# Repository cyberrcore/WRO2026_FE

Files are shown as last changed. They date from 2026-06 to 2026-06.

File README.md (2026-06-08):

# WRO 2026 Future Engineers - Team CYBERRCORE

<p align="center">
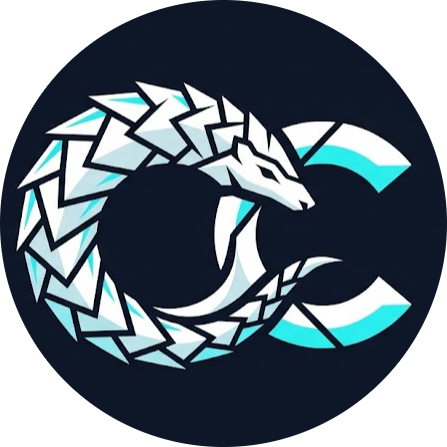
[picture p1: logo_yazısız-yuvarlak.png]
Team CYBERRCORE Logo
  
</p>

# 🏆 Turkish National 2nd Place - WRO 2026 FE

<p align="center">
Turkish robotics team building compact autonomous vehicles for<br>
<b>World Robot Olympiad™ Future Engineers 2026</b>
</p>

---

CYBERRCORE developed a compact autonomous vehicle designed for both the **Open Round** and **Obstacle Round**. Built through a short but intense engineering process, our robot combines **mechanical design**, **embedded control**, **computer vision**, and **sensor-based navigation** into a simple, reliable, and competition-ready system.

---

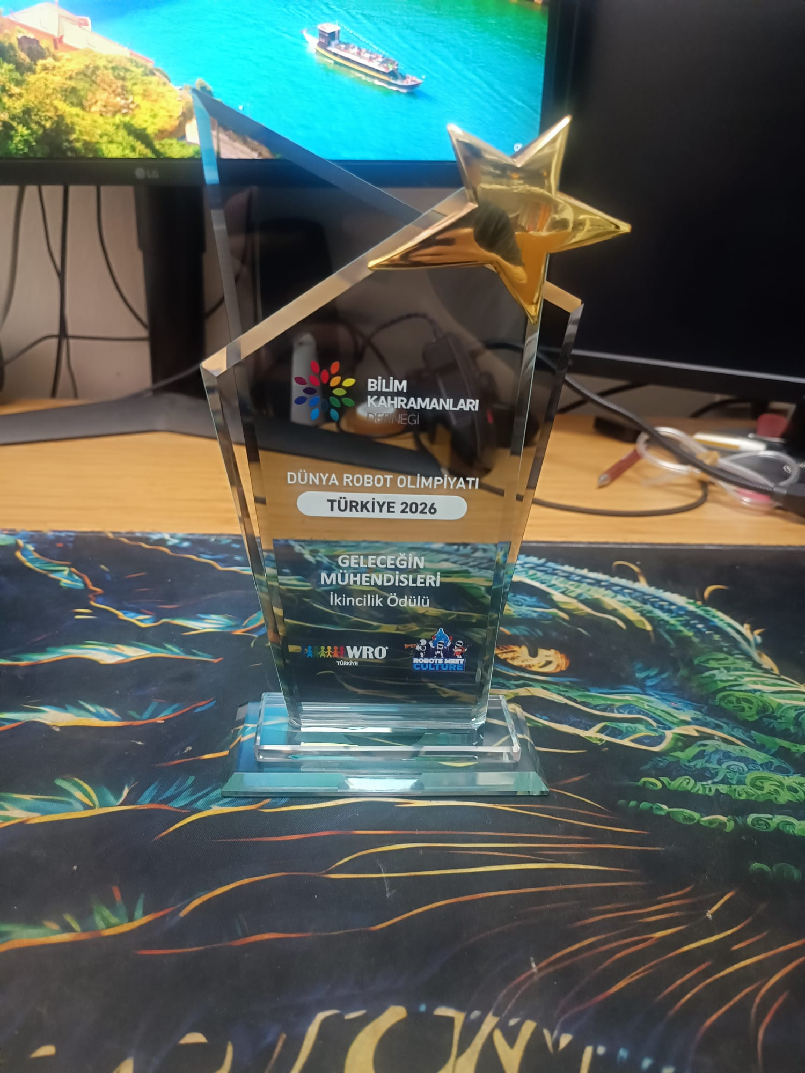
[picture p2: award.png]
Team CYBERRCORE Award


---

## Robot Documentation Preview

| Mechanical CAD | Electronics Wiring |
| --- | --- |
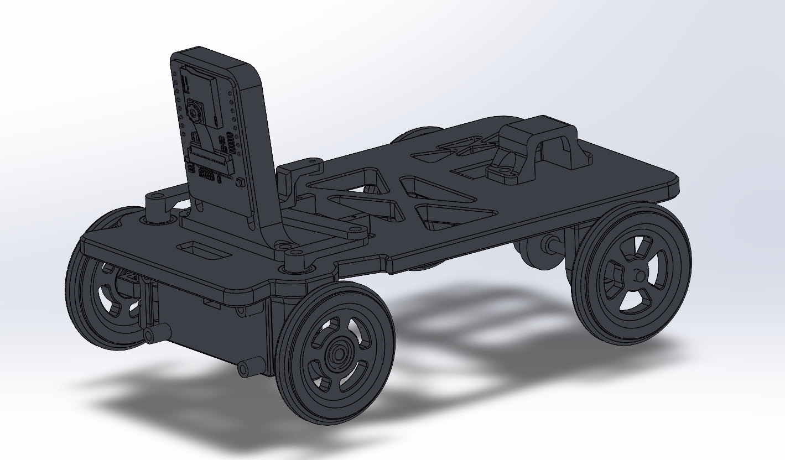
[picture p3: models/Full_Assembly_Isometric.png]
Full robot CAD assembly
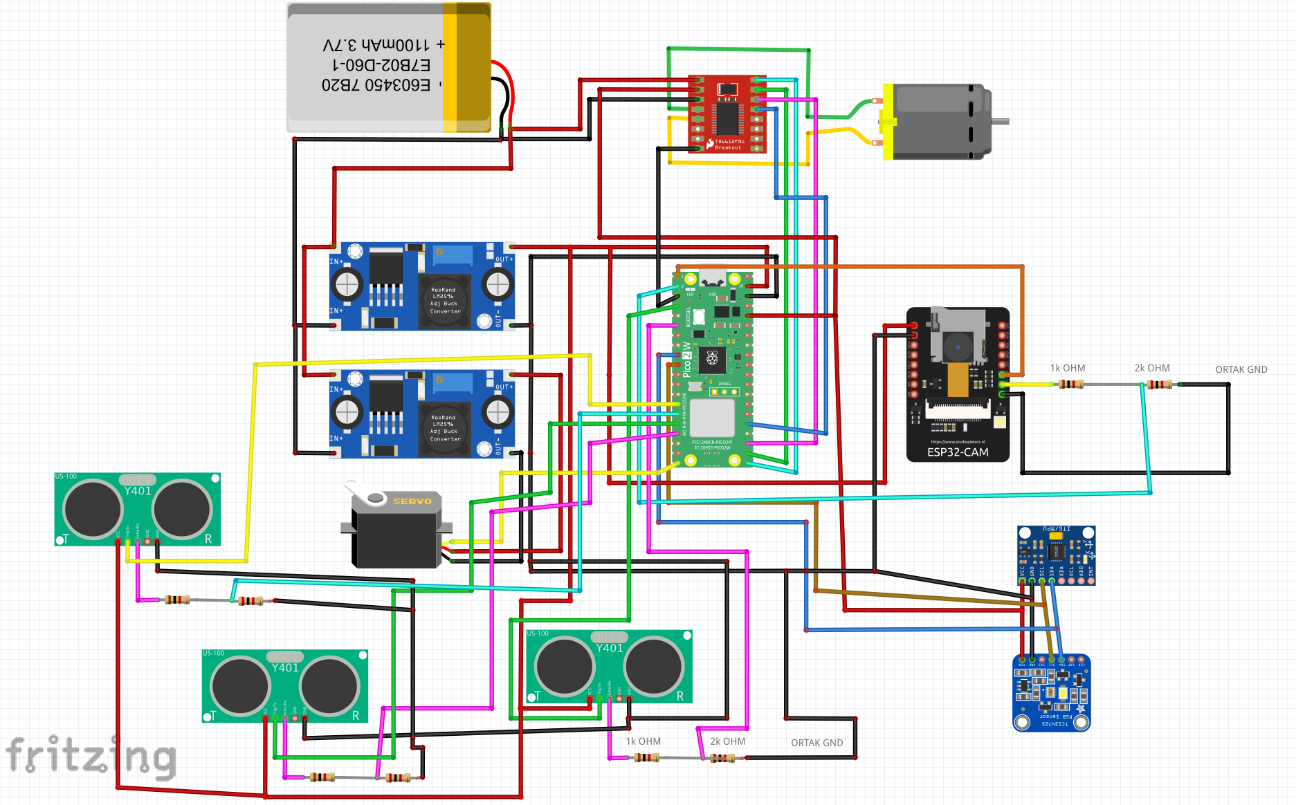
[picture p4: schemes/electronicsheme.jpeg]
Complete electronics wiring scheme
|  |  |

| Bench Build | Track Testing |
| --- | --- |
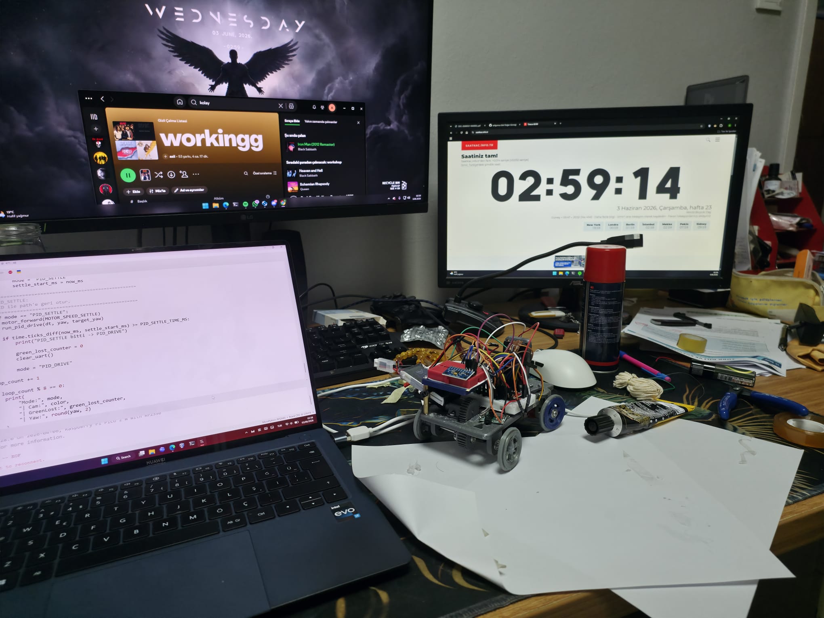
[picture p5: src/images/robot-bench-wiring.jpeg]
Robot bench wiring and development setup
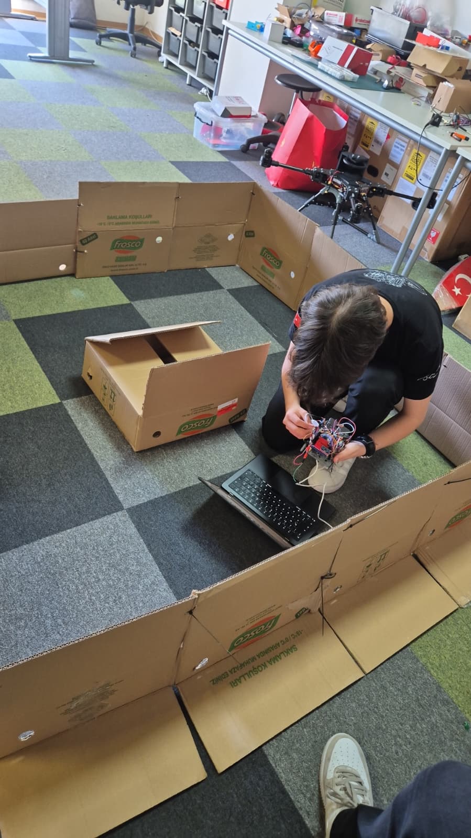
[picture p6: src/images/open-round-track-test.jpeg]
Open-round track testing
|  |  |

---

## Repository Map

| Folder / File | Contents | Why it matters |
| --- | --- | --- |
| [`src/`](src/) | ESP32-CAM firmware, Raspberry Pi Pico MicroPython scripts, state-machine logic, PID control, test utilities | Shows how the autonomous behavior is implemented and tuned |
| [`schemes/`](schemes/) | Full wiring scheme, electronics BOM, signal tables, voltage rails, current budget | Allows judges or other teams to reproduce the electrical system safely |
| [`models/`](models/) | CAD renders, mechanical explanations, chassis, steering, drivetrain, mounts, wheels | Documents the robot's physical design and engineering reasoning |
| [`models/STL/`](models/STL/) | Print-ready STL files for all custom mechanical parts | Enables direct reproduction of the 3D-printed robot body |
| [`v-photos/`](v-photos/) | Six required robot views: front, rear, top, bottom, left, right | Physical evidence of the built prototype |
| [`t-photos/`](t-photos/) | Official and fun team photos | Team identification |
| [`video/`](video/) | Links to open-round and obstacle-round run videos | Demonstrates real robot performance |
| [`CYBERRCORE_Technical_Documentation.pdf`](CYBERRCORE_Technical_Documentation.pdf) | Complete technical report | Printable engineering documentation |

---

## Engineering Rubric Coverage

| WRO judging criterion | Repository evidence |
| --- | --- |
| Mobility and mechanical design | `models/README.md`, CAD previews, STL files, chassis layout, Ackermann steering, differential drivetrain |
| Power and sensor architecture | `schemes/README.md`, wiring scheme, BOM, voltage rails, signal tables, power budget |
| Software architecture | `src/README.md`, ESP32-CAM firmware, Pico MicroPython files, UART protocol, PID parameters |
| Obstacle strategy | Camera color detection, red/green target logic, obstacle state machine, gyro recovery |
| Repeatability and testing | Servo tuning script, camera UART test, validation tables, reproduction checklist |
| Engineering decisions | Trade-off tables explaining why each subsystem was selected |

---

## 1. System Overview

Team CYBERRCORE's robot is a fully autonomous four-wheeled vehicle built for WRO 2026 Future Engineers. The architecture is split into mechanical, electrical, and software subsystems so each part can be tested independently before full autonomous runs.

The robot uses:

| Subsystem | Technology | Role |
| --- | --- | --- |
| Main controller | Raspberry Pi Pico 2 W H | Runs MicroPython navigation, PID steering, sensor fusion, motor control, and lap counting |
| Vision module | ESP32-CAM | Detects red and green obstacles using RGB565 image processing |
| Motor driver | TB6612FNG | Controls the brushed DC drive motor with PWM and direction pins |
| Drive motor | 6 V micro DC motor | Provides rear-wheel propulsion through a spur-gear drivetrain |
| Steering | HD-1440A servo | Drives the front Ackermann steering linkage |
| Distance sensor | US-100 ultrasonic sensor | Detects walls, corners, and close-range safety distance |
| IMU / gyro | MPU6050 | Estimates yaw for 90 degree turns and heading recovery |
| Color sensor | TCS34725 | Backup / future validation module for color sensing |
| Battery | 2S 450 mAh 40C LiPo | Main power source, 7.4 V nominal and 8.4 V fully charged |
| Voltage regulation | 2x LM2596 / RT3505 buck converters | Separate logic and servo power rails |
| Mechanical structure | SolidWorks + FDM 3D printing | Custom chassis, mounts, gears, wheels, and steering parts |

### High-level control architecture

```mermaid
flowchart LR
    ESP[ESP32-CAM<br>RGB565 color detection] -->|UART 115200<br>RED / GREEN / NONE| PICO[Raspberry Pi Pico 2 W H<br>Navigation + PID + sensor fusion]
    US[US-100 Ultrasonic] --> PICO
    IMU[MPU6050 Gyro] --> PICO
    TCS[TCS34725 Backup Color Sensor] --> PICO
    PICO -->|PWM + Direction| TB[TB6612FNG Motor Driver]
    TB --> MOTOR[Rear DC Motor]
    PICO -->|50 Hz PWM| SERVO[HD-1440A Steering Servo]
    BAT[2S LiPo Battery] --> B1[Buck 1: 5 V Logic Rail]
    BAT --> B2[Buck 2: 5 V / 6 V Servo Rail]
    BAT --> TB
```

The ESP32-CAM handles vision separately so the Pico does not need to process camera frames. The Pico receives simple UART messages and combines them with ultrasonic distance and gyro yaw to decide when to drive straight, avoid obstacles, turn corners, recover heading, or stop after the required number of laps.

---

## 2. Mechanical Design

The mechanical platform is designed around three priorities:

1. **Low center of gravity** for stable driving at speed.
2. **Repeatable steering geometry** for consistent cornering.
3. **Easy reproduction** using printable CAD/STL files.

All custom mechanical components were designed in SolidWorks and manufactured using FDM 3D printing. PLA is used for prototyping, while PETG or ABS is recommended for competition versions where stronger temperature and impact resistance are useful.

---

### 2.1 Main Chassis

The main chassis uses a single-level flat-plate structure. This keeps the robot low and leaves enough surface area for electronics, wiring, motor placement, servo placement, and sensor mounts.

| Feature | Description |
| --- | --- |
| Architecture | Single-level flat plate |
| Center of gravity | Low CG improves stability during fast turns |
| Lightening cutouts | X-pattern triangular pockets reduce mass while preserving load paths |
| Standoff columns | Molded-in posts allow direct PCB and cover mounting |
| Subsystem zones | Dedicated areas for motor, servo, differential, and sensor brackets |
| Perimeter rail | Continuous edge flange supports external bracket attachment |
| Recommended print settings | 40-60% infill, gyroid pattern, layer lines perpendicular to primary stress direction |

The X-pattern cutouts reduce weight without removing material from the major structural paths. This helps the robot remain light enough for speed while still resisting flex during steering and drivetrain loads.

---

### 2.2 Steering System - 4-Part Ackermann Linkage

The front steering system uses an Ackermann-style linkage. In a turn, the inner front wheel needs to rotate at a sharper angle than the outer wheel because it travels around a smaller radius. The custom linkage is designed to make the front wheels point toward a common turning center, reducing tire scrub and improving repeatability.

| Part | Role | Key feature |
| --- | --- | --- |
| `Steer1` - Steering knuckle | Connects wheel spindle to chassis upright | L-shaped bracket; upper hole for servo pin and lower hole for chassis pivot |
| `Steer2` - Tie rod | Transmits servo motion to both front knuckles | Flat bar with equal-diameter holes; designed for low backlash |
| `Steer3` - Left arm | Converts servo rotation to left wheel angle | Asymmetric boss compensates for Ackermann geometry |
| `Steer4` - Right arm | Mirrored steering arm for the right side | Cylindrical boss for shaft engagement; mirrored from the left side |

This steering design is more complex than a simple direct-servo steering setup, but it gives more realistic vehicle behavior and better corner consistency.

---

### 2.3 Rear Drivetrain and Differential

The rear drivetrain uses a 1:1 spur-gear pair to transfer motor torque to the rear axle. The gear set uses **31-tooth to 31-tooth gears** with a **0.8 module**.

| Parameter | Value | Reason |
| --- | --- | --- |
| Gear module | 0.8M | Compact pitch suitable for small printed drivetrains |
| Tooth count | 31T : 31T | 1:1 ratio preserves motor RPM |
| Drive ratio | 1:1 | Prioritizes speed while relying on low vehicle mass for sufficient torque |
| Bearing type | 3x10x4 radial ball bearings | Reduces friction and improves lap-to-lap consistency |
| Differential | Custom printed differential | Allows rear wheels to rotate at different speeds during turns |

The differential is important because the inside and outside rear wheels travel different distances in a turn. Without differential action, the inside rear wheel can scrub against the floor, causing inconsistent cornering and possible heading errors.

---

### 2.4 Wheels and Tires

The front and rear wheels are designed differently because they have different jobs.

| Aspect | Front wheel | Rear wheel |
| --- | --- | --- |
| Hub type | Recessed bearing seat for press-fit 3x10x4 bearing | Direct shaft hub, no bearing |
| Spoke pattern | 4 spokes with intermediate web | 4 solid spokes, lighter |
| Function | Free rotation around a fixed spindle | Fixed to driven axle shaft |
| Tire fit | O-ring press-fit over outer rim flange | O-ring press-fit over outer rim flange |

The tires use an O-ring / torus profile with circumferential grip grooves. This makes tire replacement fast and keeps the rolling geometry consistent between test sessions.

---

### 2.5 Sensor and Electronics Mounts

The robot uses dedicated printed mounts for the camera, ultrasonic sensor, and motor. This improves repeatability because sensor angles and drivetrain alignment are defined by printed geometry instead of temporary hand placement.

| Mount | Key features |
| --- | --- |
| Camera mount `CamMount` | Tall vertical bracket, two vertical adjustment slots, angled forward lean for near-field obstacle detection, two M3 base holes |
| US-100 mount `US100_Mount` | Box bracket, square sensor cutout, side snap-tab retention, four corner mounting holes |
| Motor mount `motorMount` | U-bracket wrapping motor on three sides, snap-clip tool-free removal, two M3 base holes, built-in gear alignment |

The camera mount height can be adjusted to tune how early the ESP32-CAM sees obstacles. The ultrasonic mount keeps the US-100 facing forward so wall distance measurements stay consistent.

---

## 3. Electronics and Wiring

The electronics architecture separates motor power, logic power, and servo power to reduce noise and avoid brownouts. All modules share a common ground reference.

### 3.1 Bill of Materials

| Component | Quantity | Type | Description |
| --- | ---: | --- | --- |
| Raspberry Pi Pico 2 W H | 1 | Main MCU | MicroPython controller for steering, motor, sensors, and navigation |
| ESP32-CAM | 1 | Camera module | RGB565 color detection and UART obstacle reporting |
| TB6612FNG | 1 | Motor driver | PWM + direction control for brushed DC motor |
| 6 V micro DC motor | 1 | Drive motor | Rear-wheel propulsion through spur gears |
| HD-1440A servo | 1 | Steering servo | PWM-controlled Ackermann steering |
| US-100 ultrasonic sensor | 1 | Distance sensor | Wall detection, corner trigger, safety stop |
| MPU6050 | 1 | IMU / gyro | Yaw estimation for turns and heading recovery |
| TCS34725 | 1 | Color sensor | Backup / future color validation |
| LM2596 / RT3505 buck converter | 2 | Voltage regulator | Buck 1 for 5 V logic, Buck 2 for servo rail |
| 2S 450 mAh 40C LiPo | 1 | Battery | Main power source |
| On/off switch | 1 | Power switch | Manual power cut |
| 3x10x4 bearings | 4+ | Hardware | Front wheel and rear shaft support |
| M3 fasteners / washers | TBD | Hardware | Chassis, mounts, and brackets |

---

### 3.2 Power Architecture

The 2S LiPo battery provides **7.4 V nominal** and **8.4 V when fully charged**. It feeds three main destinations through the on/off switch:

1. Buck 1 input for the 5 V logic rail.
2. Buck 2 input for the servo rail.
3. TB6612FNG VM motor power input directly.

#### Main power input

| From | To | Voltage | Peak current | Notes |
| --- | --- | --- | --- | --- |
| 2S LiPo + | On/off switch input | 7.4-8.4 V | 2.5 A | Full-load peak across all rails |
| Switch output | Buck 1 input | 7.4-8.4 V | 0.6 A | Logic rail input |
| Switch output | Buck 2 input | 7.4-8.4 V | 1.0 A | Servo rail input |
| Switch output | TB6612FNG VM | 7.4-8.4 V | 1.0 A | Direct battery power for motor |
| 2S LiPo - | Common GND bus | 0 V | - | Shared ground reference |

#### Buck 1 - 5 V logic rail

| From | To | Voltage | Current | Notes |
| --- | --- | --- | --- | --- |
| Buck 1 OUT+ | Pico VBUS | 5.0 V | 50-100 mA | Powers Pico onboard 3.3 V regulator |
| Buck 1 OUT+ | ESP32-CAM 5V | 5.0 V | 100-400 mA | Camera current depends on operation |
| Buck 1 OUT+ | TB6612FNG VCC | 5.0 V | 1-5 mA | Logic supply only |

Total estimated Buck 1 output load: **400-500 mA**.

#### Buck 2 - servo rail

| From | To | Voltage | Current | Notes |
| --- | --- | --- | --- | --- |
| Buck 2 OUT+ | HD-1440A servo red wire | 5.0 V default, optional 6.0 V | 10-1000 mA | Up to 1 A peak under load |

Buck 2 should be set to **5 V by default**. A 6 V servo rail can be used for more steering torque and speed only if the wiring, servo, and regulator are verified to support it.

#### Pico 3.3 V sensor rail

| From | To | Voltage | Current | Notes |
| --- | --- | --- | --- | --- |
| Pico 3V3 OUT | TCS34725 VCC | 3.3 V | ~5 mA | Color sensor |
| Pico 3V3 OUT | MPU6050 VCC | 3.3 V | ~4 mA | Gyro + accelerometer |
| Pico 3V3 OUT | US-100 VCC | 3.3 V | ~20 mA | Ultrasonic measurement pulse |
| Pico GND | All sensor grounds | 0 V | - | Common reference |

Total estimated Pico 3.3 V sensor load: **30-40 mA**, within the Pico regulator capacity.

---

### 3.3 Signal and Data Lines

| From | To | Voltage | Notes |
| --- | --- | --- | --- |
| Pico GPIO 14 PWM | HD-1440A servo signal | 3.3 V | 50 Hz PWM, 1-2 ms pulse |
| Pico GPIO 16 PWM | TB6612FNG PWMA | 3.3 V | Motor speed control |
| Pico GPIO 17 | TB6612FNG AIN2 | 3.3 V | Motor direction |
| Pico GPIO 18 | TB6612FNG AIN1 | 3.3 V | Motor direction |
| Pico GPIO 19 | TB6612FNG STBY | 3.3 V | Must be HIGH to enable motor output |
| Pico GPIO 4 SDA | MPU6050 SDA / TCS34725 SDA | 3.3 V | Shared I2C data |
| Pico GPIO 5 SCL | MPU6050 SCL / TCS34725 SCL | 3.3 V | Shared I2C clock |
| Pico GPIO 10 | US-100 TRIG | 3.3 V | 10 microsecond trigger pulse |
| Pico GPIO 11 | US-100 ECHO | 3.3 V | Echo input |
| ESP32-CAM TX | 1k + 2k divider to Pico GPIO 1 RX | 5 V to 3.3 V | Level shift required |
| Pico GPIO 0 TX | ESP32-CAM RX | 3.3 V | Compatible with ESP32-CAM RX |

> Important: measure both buck converter outputs with a multimeter before connecting the Pico, ESP32-CAM, sensors, or servo.

---

### 3.4 Power Budget

| Rail | Consumers | Typical current | Peak current |
| --- | --- | ---: | ---: |
| Battery direct to TB6612FNG VM | DC motor | ~300 mA | 1.0 A |
| Buck 1 - 5 V logic | Pico + ESP32-CAM + TB6612FNG logic | ~250 mA | ~505 mA |
| Buck 2 - servo rail | HD-1440A servo | ~10 mA idle | 1.0 A |
| Pico 3.3 V out | MPU6050 + TCS34725 + US-100 | ~29 mA | ~40 mA |
| Total battery load | All rails combined | ~590 mA | ~2.5 A |

This power separation helps prevent motor and servo current spikes from resetting the logic boards.

---

## 4. Software Architecture

The software is divided between the ESP32-CAM and the Raspberry Pi Pico.

| File | Platform | Purpose |
| --- | --- | --- |
| `camera.cpp` | ESP32-CAM / Arduino C++ | RGB565 color detection for red and green obstacles; UART output |
| `camera_uart_blink.py` | Pico / MicroPython | Isolated UART receiver test; blinks LED on camera messages |
| `openround.py` | Pico / MicroPython | Open-round navigation with gyro-assisted 90 degree turns |
| `obstacleround.py` | Pico / MicroPython | Obstacle-round navigation, camera tracking, gyro recovery, lap counting |
| `servo_tune.py` | Pico / MicroPython | Servo center, direction, and steering tuning utility |

---

### 4.1 ESP32-CAM Vision System

The ESP32-CAM captures **QQVGA 160x120** RGB565 frames and scans the lower image region beginning at `ROI_Y_START = 30`. Pixels are sampled with a 2x2 step, converted from RGB565 to RGB888, and tested against threshold rules.

The output is sent to the Pico over UART at **115200 baud**.

#### UART protocol

One line is sent per frame:

```text
RED,<center_x>,<pixel_count>
GREEN,<center_x>,<pixel_count>
NONE
```

| Detection | Rule |
| --- | --- |
| Red | High red channel, low green/blue channels, red dominates other channels |
| Green | High green channel, limited red/blue channels, green dominates other channels |
| Priority | If both colors are visible, red is prioritized when red area is at least equal to green area |
| Minimum area | Color must exceed `RED_MIN_AREA` or `GREEN_MIN_AREA` before being reported |

The Pico does not process image frames directly. It only receives the detected color, horizontal center position, and pixel area.

---

### 4.2 Open Round Navigation

`openround.py` implements a deterministic state machine for repeated 90 degree turns. The robot drives straight until the US-100 detects a wall closer than `TURN_DISTANCE_CM`. Then it turns using gyro yaw until the target turn angle is reached.

After `STOP_AFTER_TURNS = 16`, the robot enters the final stop sequence.

```mermaid
stateDiagram-v2
    [*] --> STRAIGHT
    STRAIGHT --> TURN: distance < TURN_DISTANCE_CM
    TURN --> STRAIGHT: turned angle >= TURN_ANGLE - TURN_TOLERANCE
    TURN --> FINAL_STRAIGHT: final corner completed
    FINAL_STRAIGHT --> STOPPED: final timer complete
    STOPPED --> [*]
```

| State | Condition to leave | Next state |
| --- | --- | --- |
| `STRAIGHT` | Distance below corner threshold | `TURN` |
| `TURN` | Gyro angle reaches target turn angle | `STRAIGHT` or `FINAL_STRAIGHT` |
| `FINAL_STRAIGHT` | Final forward timer completes | `STOPPED` |
| `STOPPED` | None | None |

---

### 4.3 Obstacle Round Navigation

`obstacleround.py` extends the open-round logic with camera-based obstacle behavior. It combines:

- UART color data from ESP32-CAM.
- US-100 ultrasonic corner detection.
- MPU6050 gyro heading control.
- Multi-state obstacle passing.
- Corner and lap counting.

The robot tracks `corner_count` and `lap_count`, and stops after `REQUIRED_LAPS = 4`.

| Obstacle | Target camera X | Passing strategy |
| --- | ---: | --- |
| Red | `RED_TARGET_X = 48` | Pass on the right |
| Green | `GREEN_TARGET_X = 112` | Pass on the left |
| None visible | - | Drive forward with gyro-assisted heading correction |

Obstacle-round logic keeps the vehicle from reacting randomly to short camera dropouts. If the camera briefly loses the obstacle, the robot can keep a short bias from the last known color and then recover to the target heading.

```mermaid
stateDiagram-v2
    [*] --> FOLLOW
    FOLLOW --> TURN: distance < TURN_DISTANCE_CM
    TURN --> FOLLOW: 90 degree turn completed
    FOLLOW --> LOCK_COLOR: RED or GREEN detected
    LOCK_COLOR --> PASS_COLOR: obstacle should be passed
    PASS_COLOR --> RECOVER_HEADING: pass time / lost color condition
    RECOVER_HEADING --> FOLLOW: heading recovered
```

#### Risk handling in obstacle round

| Risk | Mitigation |
| --- | --- |
| False ultrasonic readings at close range | Reject distances below `MIN_VALID_DISTANCE_CM` |
| Same wall counted twice after a turn | `TURN_IGNORE_AFTER_TURN_MS` blocks immediate re-trigger |
| Corner trigger during obstacle avoidance | `TURN_IGNORE_AFTER_COLOR_MS` delays corner detection |
| Camera briefly loses obstacle | `LOST_COLOR` keeps short steering bias from last known color |
| Two obstacles close together | `chain_active` extends pass duration and increases bias |
| Gyro drift after maneuvers | Yaw and PID state reset after turns and recovery events |
| UART partial messages | Buffer is bounded; lines parsed only after newline termination |

---

### 4.4 PID Steering Control

The robot uses discrete PID steering control for heading correction.

```text
error = target_yaw - yaw
integral += error * dt
derivative = (error - last_error) / dt
output = (KP * error) + (KI * integral) + (KD * derivative)
```

| Parameter | Open Round | Obstacle Round |
| --- | ---: | ---: |
| `SERVO_MIN` | 30 | 50 |
| `SERVO_CENTER` | 65 | 65 |
| `SERVO_MAX` | 100 | 80 |
| `KP` | 1.8 | 2.4 (`KP_HEADING`) |
| `KI` | 0.00 | - |
| `KD` | 0.25 | 0.35 (`KD_HEADING`) |
| `MOTOR_SPEED_STRAIGHT` | 30 | 65 (`FOLLOW`) |
| `MOTOR_SPEED_TURN` | 50 | 57 |
| `TURN_DISTANCE_CM` | - | 45 |
| `STOP_DISTANCE_CM` | - | 6 |

The steering output is clamped to the servo limits. Open-round tuning prioritizes clean 90 degree turns, while obstacle-round tuning prioritizes faster heading recovery after avoidance maneuvers.

---

## 5. Vehicle Photos

The `v-photos/` folder contains six required views of the physical robot. These photos show the current prototype build used during development and testing.

| View | What it shows |
| --- | --- |
| Front | ESP32-CAM on custom bracket, US-100 under the front nose, blue steered front wheels |
| Rear | 0.8M 31T spur gear on rear axle, brushed DC motor in U-bracket, toggle switch, battery connector |
| Top | Prototype wiring, electronics platform, camera location, support columns |
| Bottom | Ackermann steering linkage, servo placement, rear gear pair, X-pattern chassis pockets |
| Left | Height stack: flat chassis, electronics platform, ESP32-CAM tower |
| Right | Rear gear train, motor, pinion, driven axle gear, front vs rear wheel hub difference |

The prototype photos may still show breadboard wiring and temporary cable routing. Final competition wiring should be cleaned and secured before official runs.

---

## 6. Validation and Testing

Validation is separated into mechanical, electronics, and software/track checks. This makes it easier to find problems before a full autonomous run.

### 6.1 Mechanical Validation

| Test | Procedure | Pass criteria |
| --- | --- | --- |
| Steering range | Move servo from min to max while wheels are lifted | Full travel without binding or wheel/chassis contact |
| Ackermann behavior | Observe inner and outer wheel angles during turns | Inner wheel turns more sharply than outer wheel in both directions |
| Gear mesh | Hand-spin drivetrain, then test at low PWM | No skipping, tight spots, or visible gear wobble |
| Differential action | Hold one wheel and rotate the opposite wheel | Allows relative motion without excessive friction |
| Bearing fit | Press bearing and spin wheel | Bearing seated, wheel rotates freely, no lateral play |
| Sensor mount rigidity | Lightly shake chassis | Camera and US-100 angle does not shift |
| Track clearance | Roll through practice corner | No chassis, wire, or mount scraping |

---

### 6.2 Electronics Validation

| Check | Method | Failure response |
| --- | --- | --- |
| Voltage rails | Measure buck outputs before connecting boards | Do not connect until output is corrected |
| I2C sensors | Confirm MPU6050 and TCS34725 addresses | Inspect SDA, SCL, power, and ground |
| UART camera | Verify `RED`, `GREEN`, and `NONE` messages | Use `camera_uart_blink.py` for isolated testing |
| Ultrasonic | Compare readings against known distances | Reject invalid values; inspect TRIG/ECHO wiring |
| Motor polarity | Test with wheels lifted | Swap motor leads or invert direction logic |
| Servo direction | Run `servo_tune.py` | Adjust reverse/settings before autonomous code |

---

### 6.3 Software and Track Validation

| Test | Procedure | Pass criteria |
| --- | --- | --- |
| Camera detection | Show red, green, and no object to ESP32-CAM | Serial output changes between `RED`, `GREEN`, and `NONE` within one frame |
| UART receiver | Run `camera_uart_blink.py` with camera connected | Red causes 1 blink, green causes 2 blinks, no spam on sustained color |
| Open round | Run `openround.py` on practice track | Completes 16 corners without double-counting walls |
| Obstacle round | Run `obstacleround.py` with red/green obstacles | Red and green are passed on the correct side; heading recovers |
| Lap counting | Full 4-lap run | Robot stops after exactly 4 laps |

---

## 7. Reproduction Checklist

Follow this order when building the robot from the repository.

1. Print all required custom parts from [`models/STL/`](models/STL/).
2. Assemble the main chassis, steering linkage, rear axle, differential, wheel hubs, and tires.
3. Check steering movement manually before installing electronics.
4. Install the motor mount, rear gear pair, and rear drivetrain.
5. Mount the ESP32-CAM and US-100 using the printed brackets.
6. Wire the electronics according to [`schemes/electronicsheme.jpeg`](schemes/electronicsheme.jpeg).
7. Verify the 5 V logic buck output with a multimeter.
8. Verify the 5 V / 6 V servo buck output with a multimeter.
9. Confirm that all modules share common ground.
10. Upload [`src/camera.cpp`](src/camera.cpp) to the ESP32-CAM.
11. Copy the selected MicroPython file to the Raspberry Pi Pico.
12. Run [`src/servo_tune.py`](src/servo_tune.py) to set center, direction, and limits.
13. Run [`src/camera_uart_blink.py`](src/camera_uart_blink.py) to test UART communication.
14. Validate open round using [`src/openround.py`](src/openround.py).
15. Validate obstacle round using [`src/obstacleround.py`](src/obstacleround.py).
16. Record final competition videos and place the links in [`video/`](video/).

---

## 8. Engineering Decisions and Trade-offs

| Decision | Why chosen | Trade-off |
| --- | --- | --- |
| Separate ESP32-CAM vision module | Offloads camera processing from the Pico and gives a simple UART interface | Requires a second board, stable serial wiring, and level shifting |
| TB6612FNG VM powered directly from battery | Reduces converter losses and gives stronger motor power | Motor speed changes slightly as battery voltage drops |
| Dual buck converters | Separates logic and servo current spikes | More wiring and both regulators must be verified |
| 1:1 spur gear drivetrain | Preserves full motor RPM for straight-line speed | Less torque multiplication; depends on low robot mass |
| Differential rear axle | Reduces inside-wheel scrub during turns | More printed parts and alignment checks |
| RGB thresholding instead of ML | Fast, simple, tunable on ESP32-CAM | Sensitive to lighting and venue color conditions |
| Gyro-based 90 degree turns | More repeatable than timing-only turns | Requires calibration and drift handling |
| US-100 corner detection | Simple direct wall measurement | Needs filtering for close-range noise |
| State-machine control | Easy to debug and explain to judges | More transition timing to tune |
| Flat-plate chassis with X cutouts | Low CG and simple mounting while reducing mass | Less rigid than a box frame; print orientation matters |
| Ackermann steering linkage | Reduces tire scrub and improves repeatability | More parts to align |
| O-ring tires | Simple replacement and consistent geometry | Less traction tuning than molded tire compounds |
| `run_log.txt` logging | Allows post-run diagnosis without live serial monitoring | File writes must not block the control loop |

---

## 9. Current Development Status

The repository contains the engineering evidence required to reproduce the robot: CAD, STL files, wiring references, software files, validation procedures, and the full technical documentation PDF.

Physical performance can still vary depending on:

- Track surface and friction.
- Battery voltage.
- Lighting conditions.
- Camera threshold tuning.
- Servo center and steering linkage alignment.
- Ultrasonic sensor noise near walls.
- Final cable routing and vibration resistance.

Before competition use, the team should complete final tuning, secure all wiring, record final open-round and obstacle-round videos, and update the `video/` folder with public links.

---

## 10. License

This project is licensed under the [MIT License](LICENSE).

---

## 11. Main Documentation

For the full printable engineering report, see:

[`CYBERRCORE_Technical_Documentation.pdf`](CYBERRCORE_Technical_Documentation.pdf)

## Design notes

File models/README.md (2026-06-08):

# Models Documentation

This folder contains the complete 3D CAD model previews for Team CYBERRCORE's WRO 2026 Future Engineers robot. All mechanical components were custom-designed in-house using **SolidWorks** to achieve a rigid, compact, and competition-ready platform optimized for sensor placement, weight distribution, and drivetrain efficiency.

## 🎯 Mechanical Design Philosophy

Our design philosophy is built around **structural rigidity with strategic weight reduction** — a flat-plate chassis architecture that keeps the center of gravity low, simplifies assembly, and provides dedicated mounting zones for every electronic and mechanical subsystem. The X-pattern lightening cutouts in the main body remove material where it is not structurally needed, reducing mass without compromising stiffness.

<p align="center">
  Full Assembly Isometric View
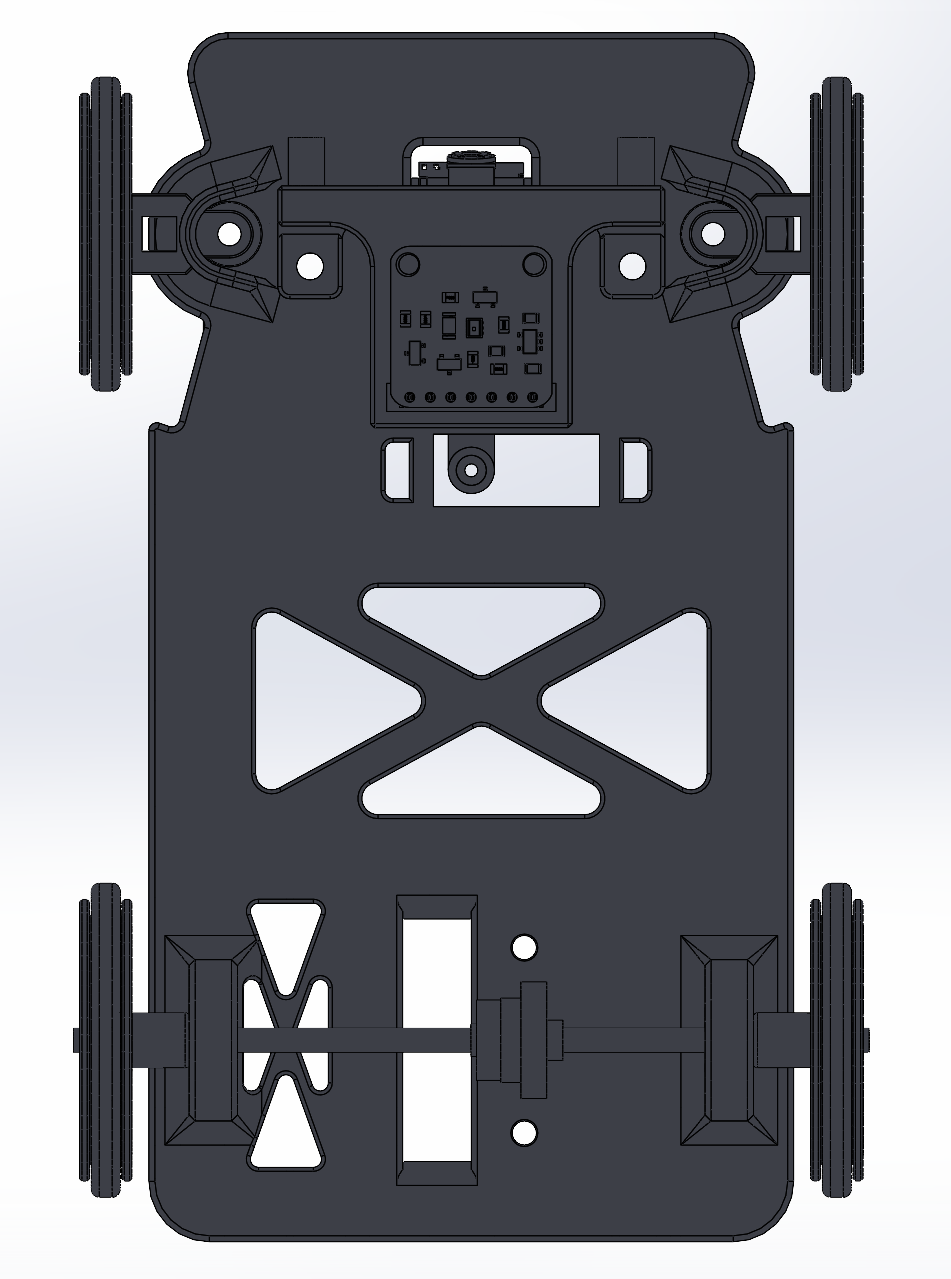
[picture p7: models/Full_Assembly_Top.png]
Full Assembly Top View
  
</p>
<p align="center">
  <em>Left: Full assembly isometric view showing overall vehicle form factor &nbsp;•&nbsp; Right: Top-down view revealing chassis layout, electronics bay, steering geometry, and drivetrain routing</em>
</p>

<p align="center">
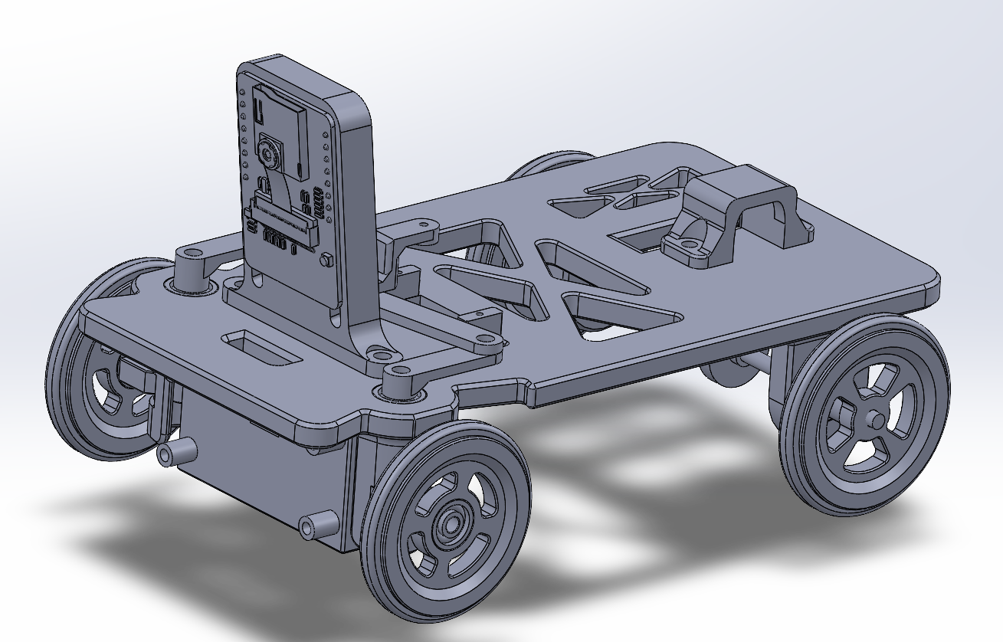
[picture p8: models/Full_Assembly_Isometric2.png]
Full Assembly Second Angle
  
</p>
<p align="center">
  <em>Secondary isometric angle highlighting camera mount, wheel profile, and chassis depth</em>
</p>

## ⚙️ Core Mechanical Systems

### 🏗️ Main Chassis

<p align="center">
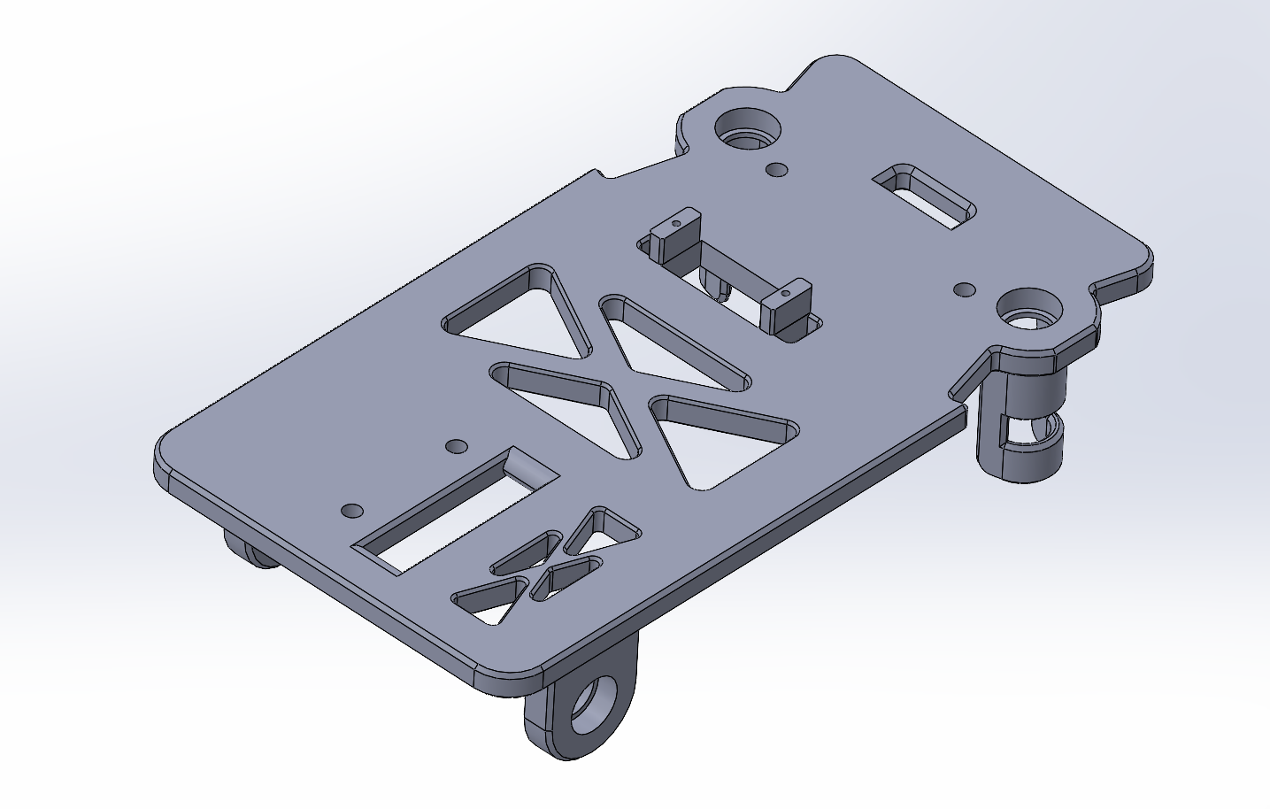
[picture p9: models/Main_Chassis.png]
Main Chassis
  
</p>
<p align="center">
  <em>Primary structural plate featuring X-pattern lightening pockets, integrated standoff posts, and dedicated mounting zones for motor, servo, electronics, and sensor assemblies</em>
</p>

**Structural Design Elements:**
- **Flat-Plate Architecture**: Single-level structural platform keeping CG as low as possible for stability at speed
- **X-Pattern Lightening Cutouts**: Triangular pocket geometry maximizes removed mass while preserving structural load paths
- **Integrated Standoff Columns**: Raised posts molded into the chassis for direct PCB and cover mounting without separate hardware
- **Dedicated Subsystem Zones**: Distinct areas pre-allocated for motor mount, servo, differential, and sensor brackets — no retrofitting required
- **Perimeter Mounting Rail**: Continuous edge flange providing multiple attachment points for external brackets and covers

---

### 🔄 Steering System — 4-Part Ackermann Linkage

The front steering system uses a 4-component linkage to achieve Ackermann-compliant geometry, ensuring both front wheels track toward a common turn center during cornering to eliminate tire scrub.

<p align="center">
  <table align="center">
    <tr>
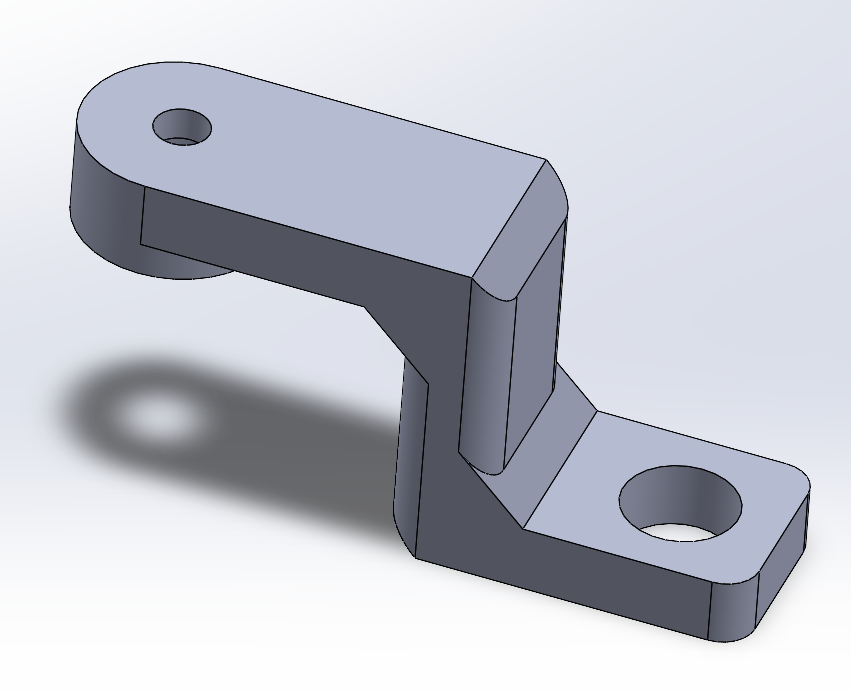
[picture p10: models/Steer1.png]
Steering Knuckle
      <td align="center"><br><em>Steer1 — Steering Knuckle</em></td>
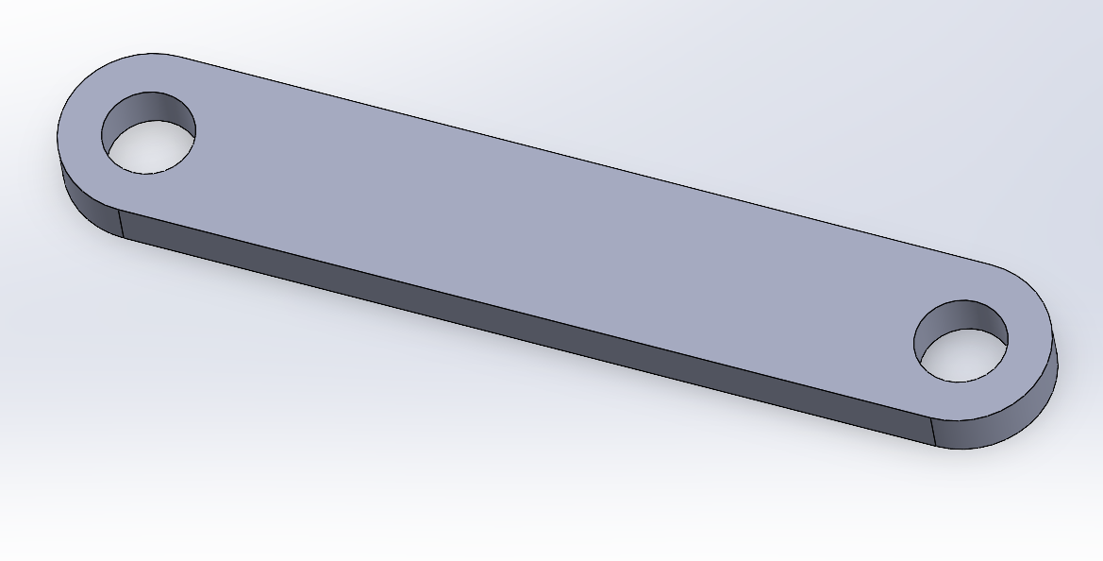
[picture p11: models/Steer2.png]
Tie Rod
      <td align="center"><br><em>Steer2 — Tie Rod</em></td>
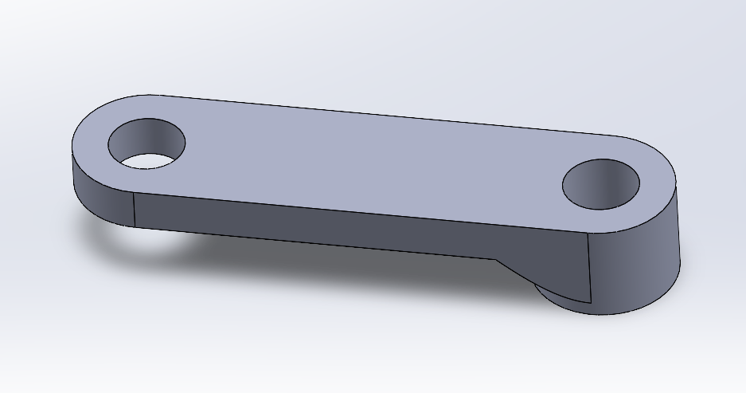
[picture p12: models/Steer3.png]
Steering Arm Left
      <td align="center"><br><em>Steer3 — Steering Arm (Left)</em></td>
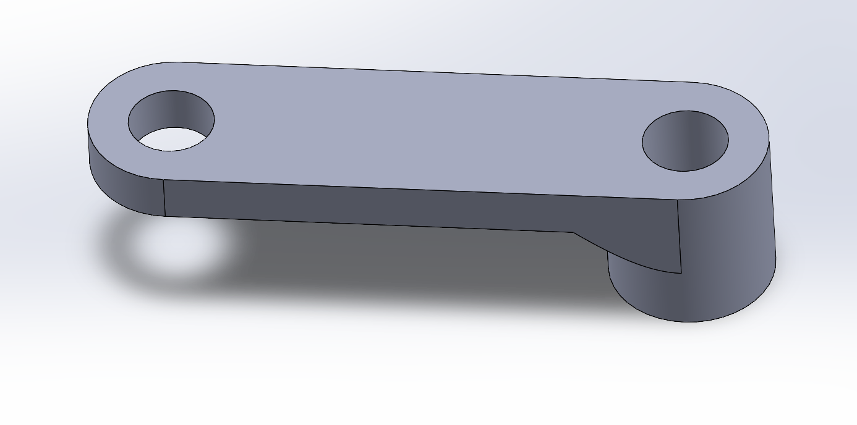
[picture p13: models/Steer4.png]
Steering Arm Right
      <td align="center"><br><em>Steer4 — Steering Arm (Right)</em></td>
    </tr>
  </table>
</p>

**Component Breakdown:**
| Part | Role | Key Feature |
|---|---|---|
| **Steer1** — Steering Knuckle | Connects wheel spindle to chassis upright | L-shaped bracket; upper hole receives servo linkage pin, lower hole bolts to chassis pivot |
| **Steer2** — Tie Rod | Transmits servo motion to wheel knuckles | Flat bar with equal-diameter holes at each end for precise, backlash-free length |
| **Steer3** — Left Steering Arm | Translates servo rotation to wheel angle | Asymmetric arm with offset boss; asymmetry compensates Ackermann geometry requirement |
| **Steer4** — Right Steering Arm | Mirror function of Steer3 for right wheel | Cylindrical boss on the long end for shaft engagement; geometry mirrored to Steer3 |

**Ackermann Compliance:** The offset geometry of Steer3/Steer4 ensures the inner wheel turns through a greater angle than the outer wheel during cornering, matching the theoretical Ackermann condition for the vehicle's wheelbase and track width.

---

### 🔧 Rear Drivetrain — Differential & Gear System

<p align="center">
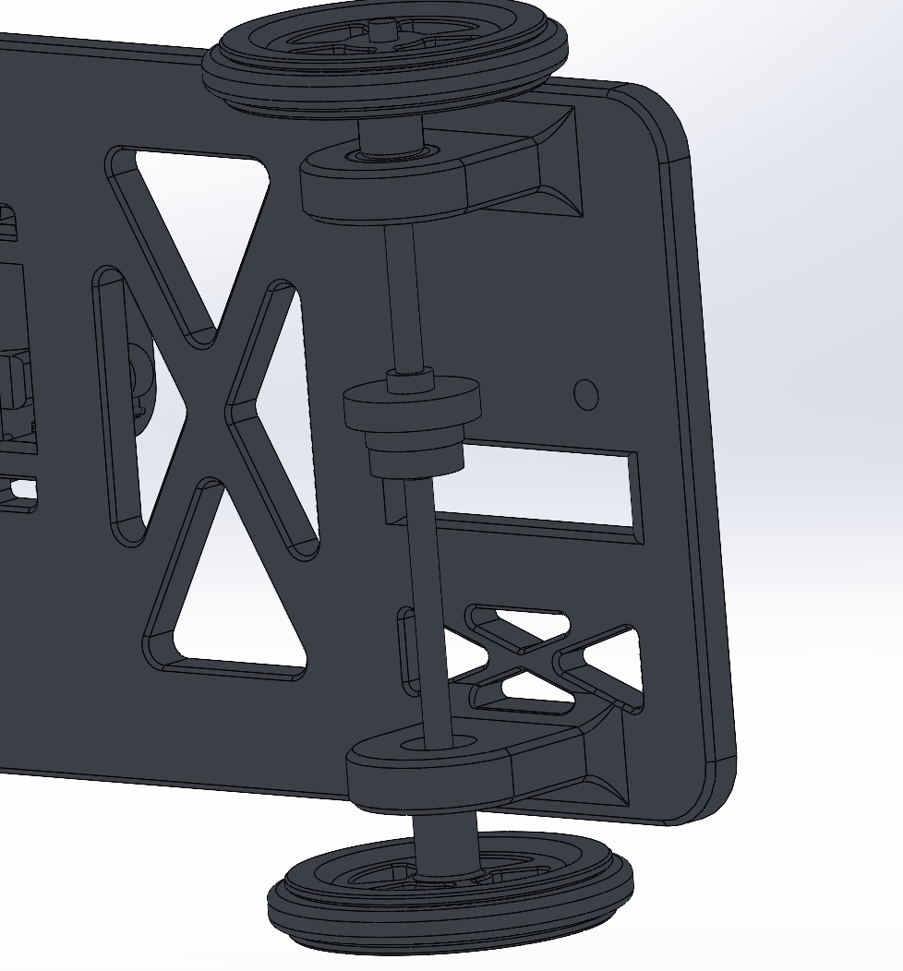
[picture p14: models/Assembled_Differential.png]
Assembled Differential
  
</p>
<p align="center">
  <em>Assembled differential showing rear shaft, gear stack, and bearing assembly — enables independent rear wheel rotation during turns to prevent inside-wheel scrub</em>
</p>

<p align="center">
  <table align="center">
    <tr>
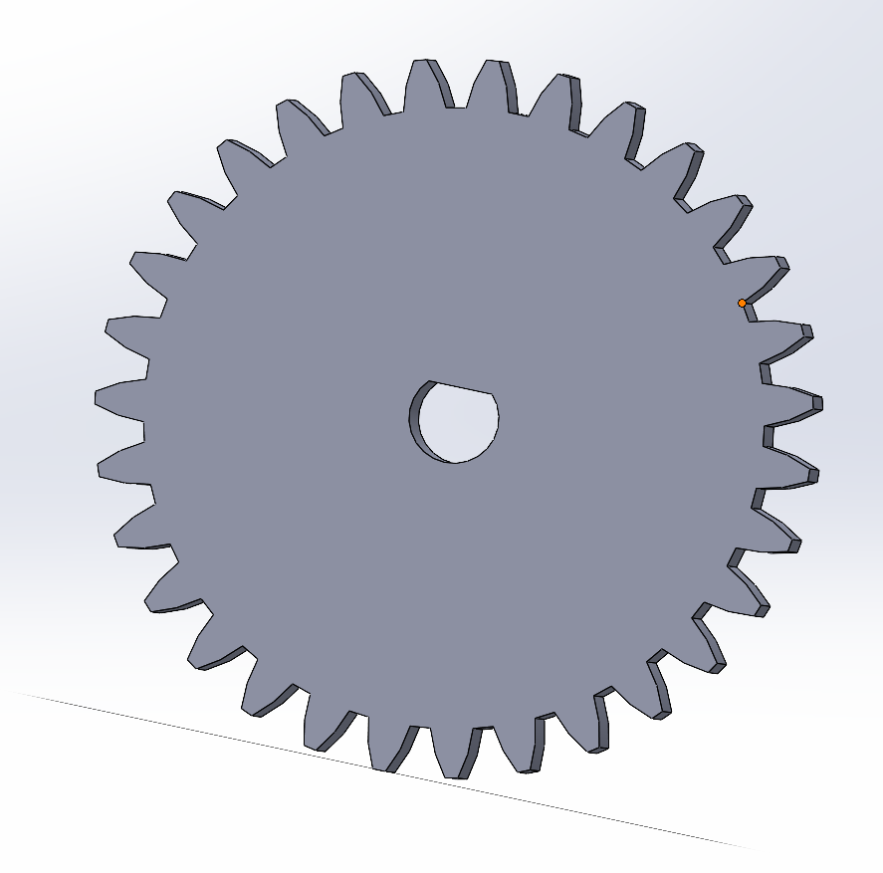
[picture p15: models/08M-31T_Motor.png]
Motor Pinion Gear
      <td align="center"><br><em>0.8M-31T Motor Gear</em></td>
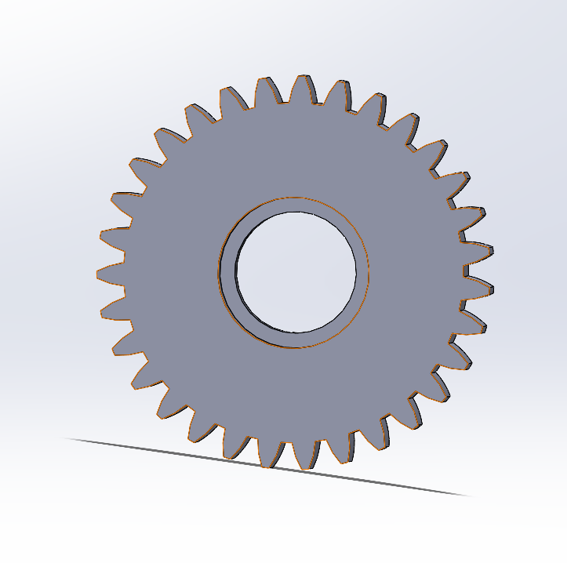
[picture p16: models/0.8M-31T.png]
Driven Gear
      <td align="center"><br><em>0.8M-31T Driven Gear</em></td>
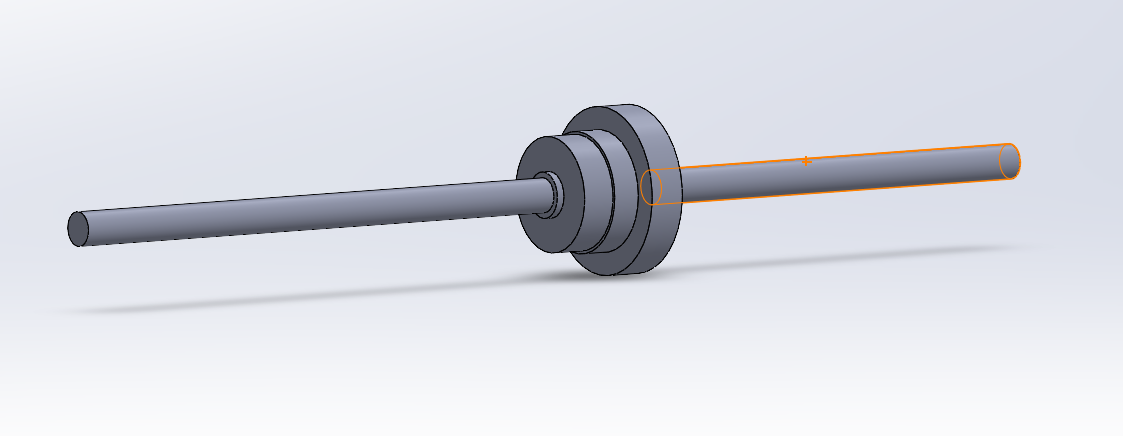
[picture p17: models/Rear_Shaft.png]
Rear Shaft
      <td align="center"><br><em>Rear Shaft Assembly</em></td>
    </tr>
  </table>
</p>

**Drivetrain Specifications:**
- **Gear Standard**: 0.8 Module spur gears — compact pitch suited for small-scale precision drivetrains
- **Tooth Count**: 31 teeth on both motor pinion and driven gear → **1:1 drive ratio**
- **Design Intent**: The 1:1 ratio preserves full motor RPM, prioritizing speed over additional torque reduction; torque is inherently sufficient at this vehicle mass
- **Motor Gear** (`08M-31T_Motor`): Small central bore sized to press-fit directly onto motor output shaft
- **Driven Gear** (`0.8M-31T`): Large central hub bore for rear shaft engagement, transfers torque into the differential
- **Rear Shaft** (`Rear_Shaft`): Through-axle with integrated differential gear stack and bearing seats at both ends; provides the structural spine of the rear drivetrain

**Torque and Speed Justification:**

| Choice | Reason | Trade-off |
| --- | --- | --- |
| 1:1 31T-to-31T gear pair | Preserves motor speed for the long straight sections of the WRO track. | Lower torque multiplication than a reduction gear, so the vehicle relies on low mass and smooth acceleration. |
| Differential rear axle | Reduces tire scrub during turns and improves repeatability in corners. | Adds more printed parts and assembly alignment checks. |
| 0.8 module gears | Strong enough for the vehicle scale while keeping gear diameter compact. | Gear mesh must be printed cleanly and aligned carefully. |
| Bearing-supported rotating joints | Reduces friction and improves consistency over repeated laps. | Requires accurate bearing seat tolerances and controlled press-fit. |

The drivetrain was selected for controllability rather than maximum acceleration. In WRO Future Engineers, predictable speed and repeatable corner entry are more valuable than a high top speed that causes missed turns or unstable sensor readings.

---

### 🏎️ Wheel & Tire System

<p align="center">
  <table align="center">
    <tr>
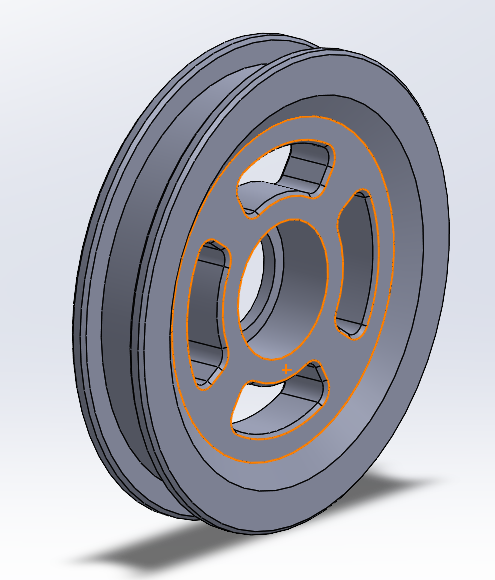
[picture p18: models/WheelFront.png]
Front Wheel
      <td align="center"><br><em>Front Wheel</em></td>
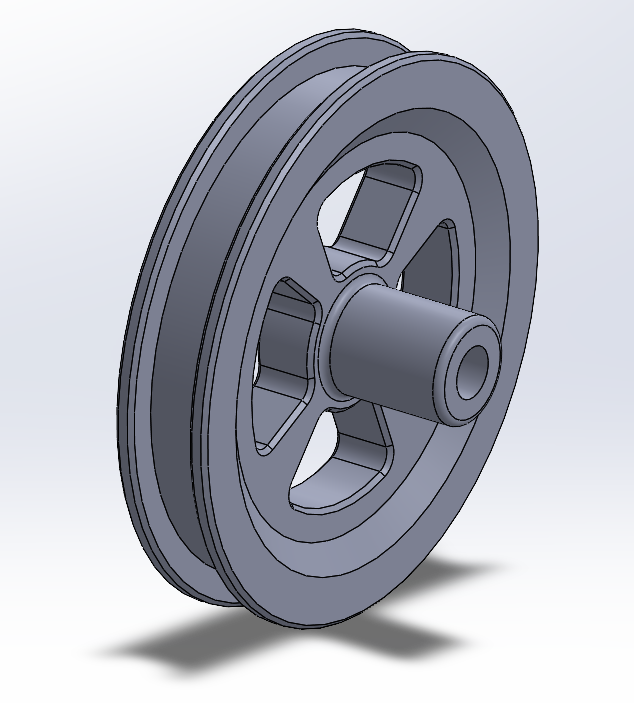
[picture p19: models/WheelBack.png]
Rear Wheel
      <td align="center"><br><em>Rear Wheel</em></td>
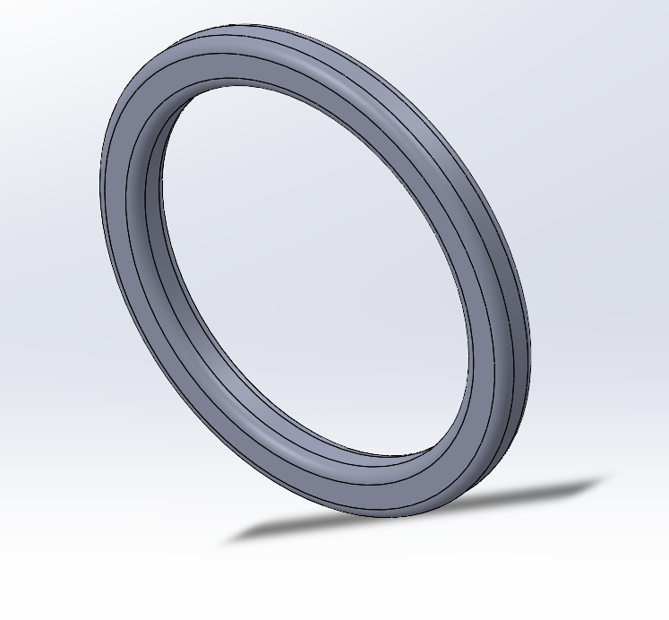
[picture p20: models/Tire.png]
Tire
      <td align="center"><br><em>Custom Tire (O-ring)</em></td>
    </tr>
  </table>
</p>

**Wheel Design Differences:**

| Aspect | Front Wheel | Rear Wheel |
|---|---|---|
| **Hub Type** | Recessed bearing seat (press-fit 3×10×4 bearing) | Direct shaft hub — no separate bearing |
| **Spoke Pattern** | 4 cut-out spokes with intermediate web | 4 solid spokes, lighter construction |
| **Steering Compatibility** | Rotates freely around fixed spindle via bearing | Fixed to rear axle shaft, driven rotationally |
| **Rim Profile** | Wide rim flange for tire retention under steering loads | Standard rim flange |

**Tire Design:**
- **Form**: O-ring style — a circular torus profile that press-fits over the outer rim flange
- **Surface**: Three parallel circumferential grooves on the outer face providing predictable traction and consistent rolling contact patch
- **Material**: Flexible rubber/TPU compound allowing elastic stretch during fitting and conforming contact with the track surface
- **Advantage**: Simple replacement without tools; consistent geometry batch-to-batch

---

### 📐 Sensor & Electronics Mounts

<p align="center">
  <table align="center">
    <tr>
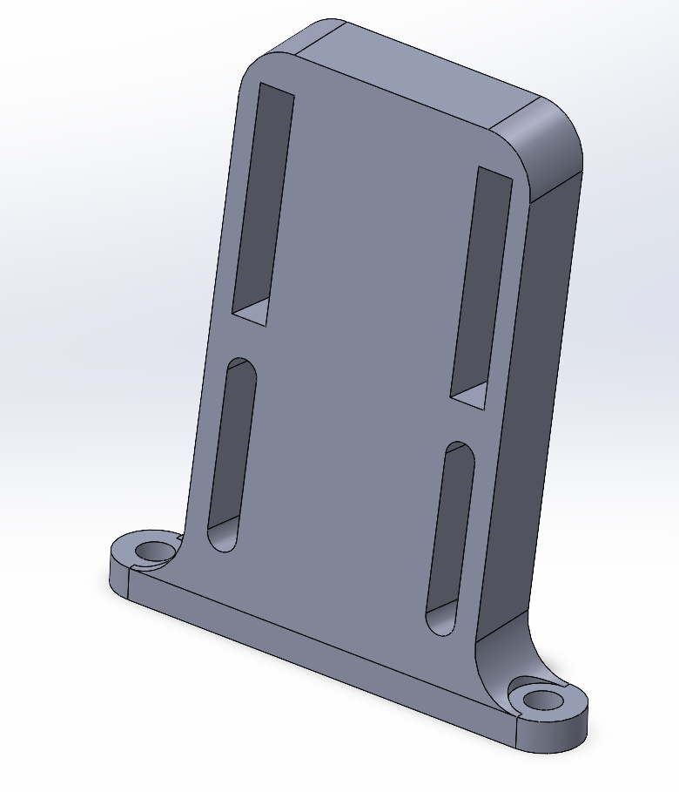
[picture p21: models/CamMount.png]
Camera Mount
      <td align="center"><br><em>Camera Mount</em></td>
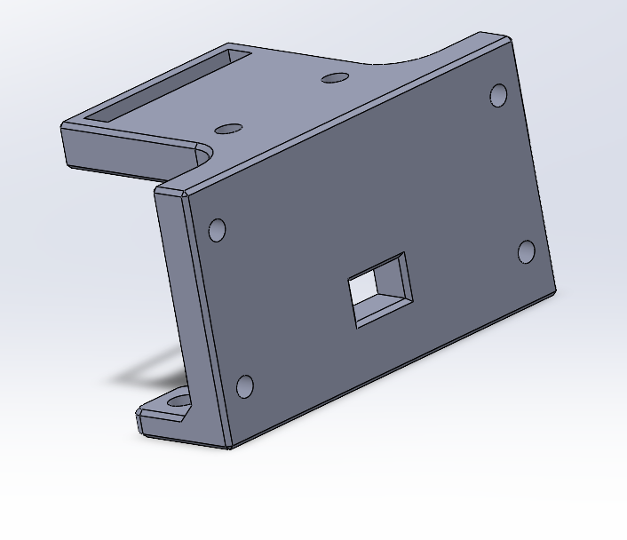
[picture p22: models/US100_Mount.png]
US-100 Mount
      <td align="center"><br><em>US-100 Ultrasonic Mount</em></td>
    </tr>
  </table>
</p>

**Camera Mount (`CamMount`):**
- Tall vertical bracket providing elevated camera positioning for wider field-of-view coverage of the competition field
- Two vertical adjustment slots allow height fine-tuning without reprinting — camera can slide and lock at the optimal angle
- Two M3 mounting holes at the base for rigid chassis attachment
- Angled forward lean designed to aim the camera slightly downward for near-field obstacle detection

**US-100 Ultrasonic Mount (`US100_Mount`):**
- Box-form bracket with square central cutout sized precisely to the US-100 sensor body
- Side snap/clip tab retains the sensor without additional fasteners for quick swap during competition
- Four corner mounting holes for secure chassis attachment
- Compact profile minimizes aerodynamic interference and weight at the front/rear of the vehicle

---

### 🔩 Motor Mount

<p align="center">
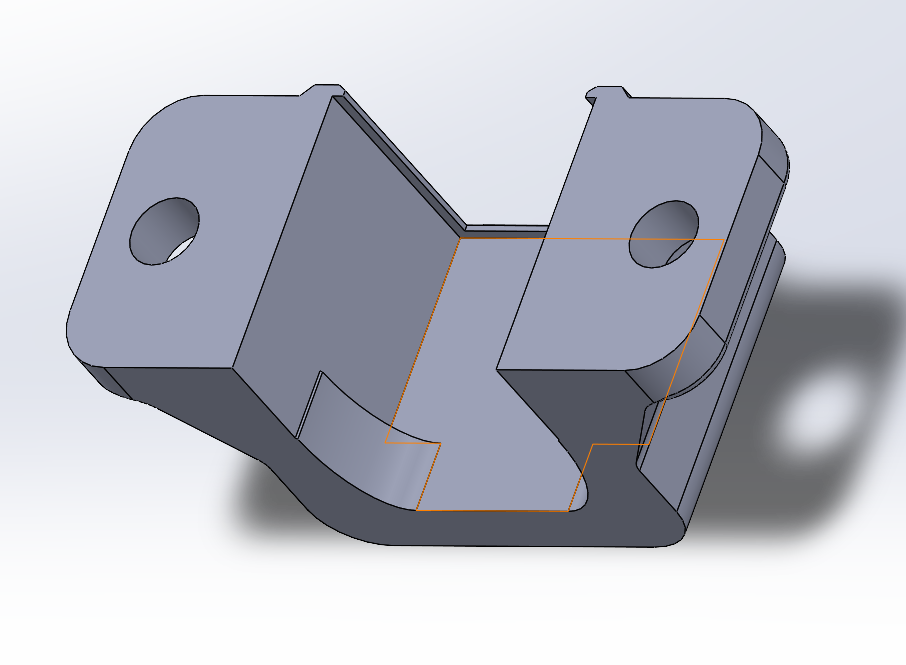
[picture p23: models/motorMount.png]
Motor Mount
  
</p>
<p align="center">
  <em>U-bracket motor mount with snap-fit clamp for DC motor body and two M3 bolt holes for chassis attachment</em>
</p>

- **U-Bracket Form**: Wraps around the motor body providing support on three sides against vibration and torque reaction
- **Snap Clip**: One side features a flexible retention tab that snaps over the motor body for tool-free field replacement
- **Dual Mounting Holes**: Two M3 holes on the base flange provide rigid, over-constrained attachment to the chassis to prevent any rocking under drive load
- **Gear Alignment**: Mount geometry positions the motor output shaft at the exact center distance required for 0.8M gear mesh with zero adjustment needed

---

### 🛞 Front Wheel Mount

<p align="center">
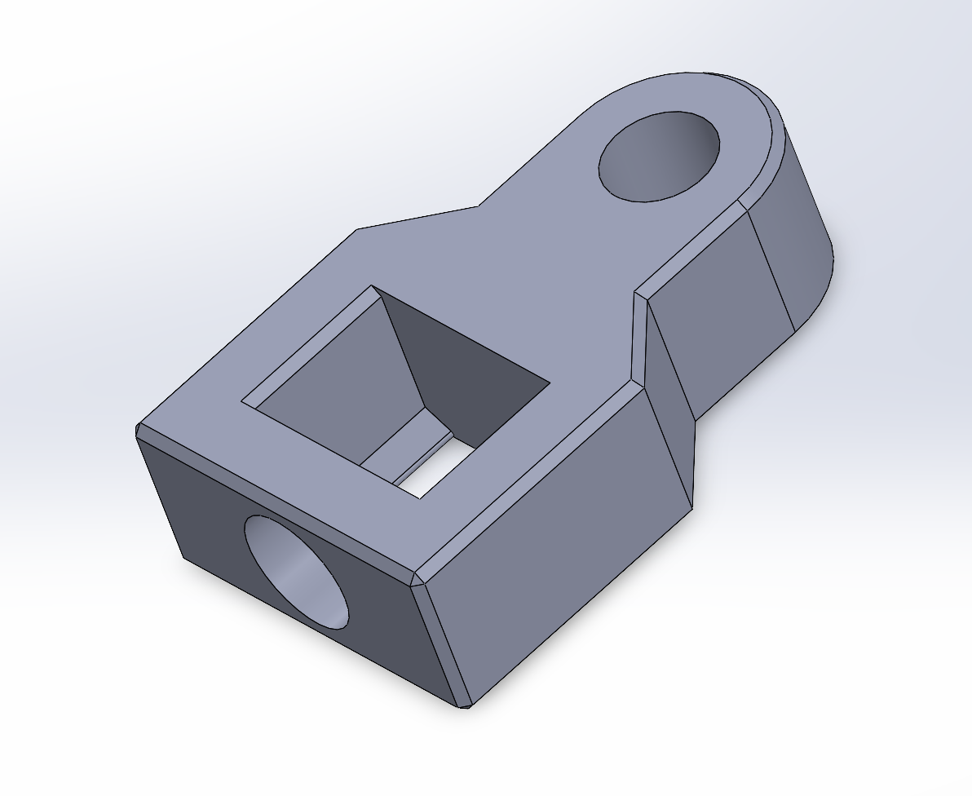
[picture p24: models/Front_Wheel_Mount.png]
Front Wheel Mount
  
</p>
<p align="center">
  <em>Front wheel upright with square steering pin slot, bearing bore, and dual attachment holes connecting the steering linkage to the wheel spindle</em>
</p>

- **Square Slot**: Receives the servo/steering pin ensuring zero rotational slip between steering command and wheel response
- **Bearing Bore**: Precision-sized pocket for 3×10×4 bearing press-fit, providing a smooth low-friction pivot axis for the front wheel
- **Dual Hole Attachment**: Two mounting points prevent single-point failure and provide the moment arm needed to resist steering loads

---

## 🔩 Hardware Components

<p align="center">
  <table align="center">
    <tr>
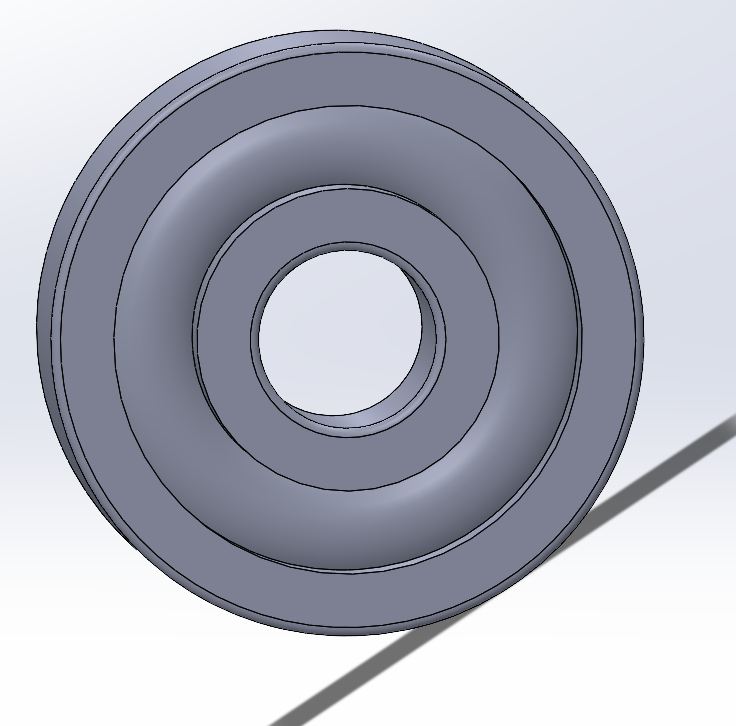
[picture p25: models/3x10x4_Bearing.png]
3x10x4 Bearing
      <td align="center"><br><em>3×10×4 Bearing</em></td>
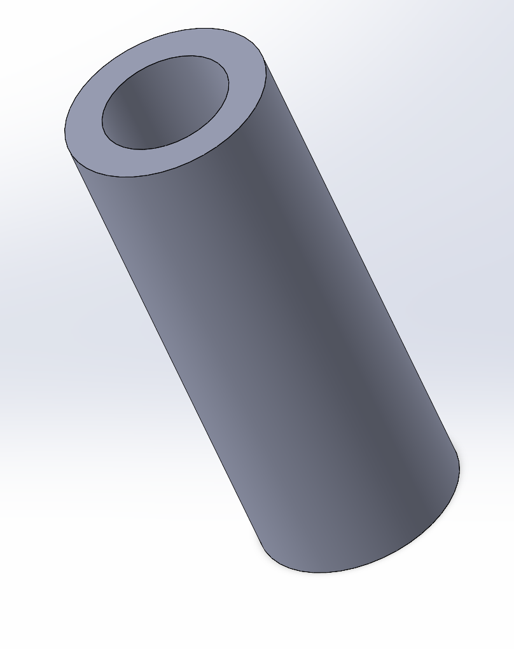
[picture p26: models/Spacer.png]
Spacer
      <td align="center"><br><em>Spacer (Thin)</em></td>
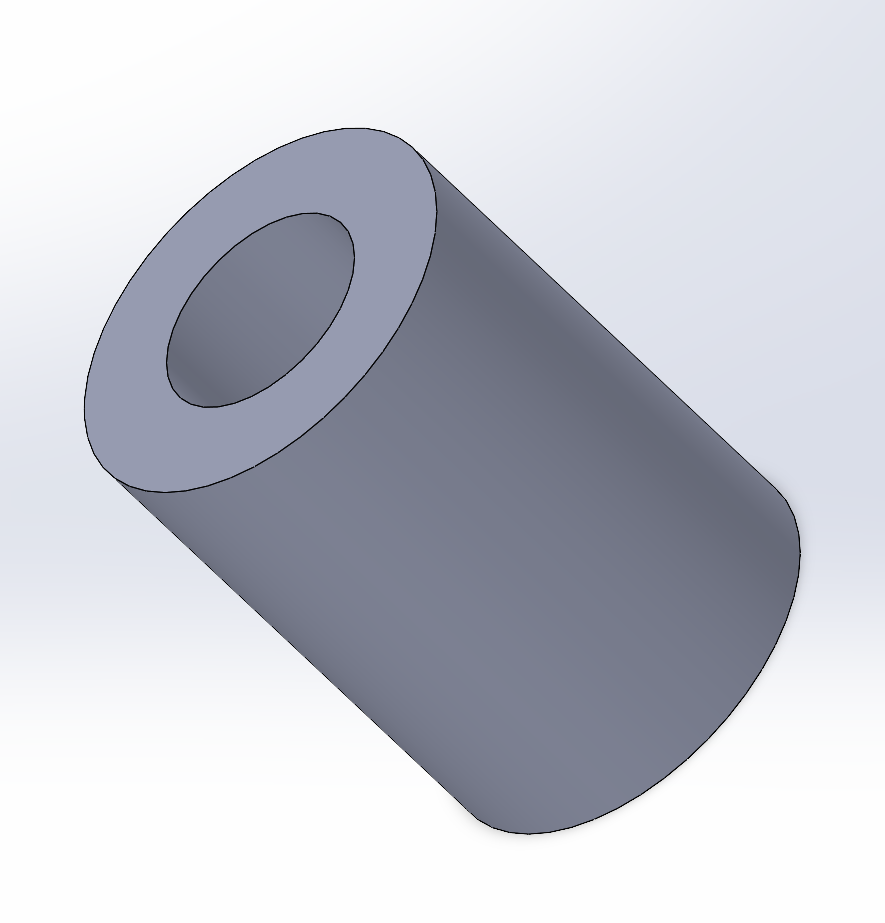
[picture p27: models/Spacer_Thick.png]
Thick Spacer
      <td align="center"><br><em>Spacer (Thick)</em></td>
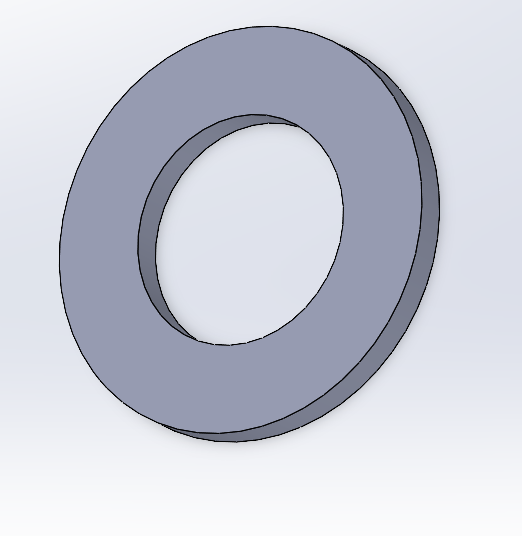
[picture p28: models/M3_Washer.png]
M3 Washer
      <td align="center"><br><em>M3 Washer</em></td>
    </tr>
  </table>
</p>

| Component | Specification | Purpose |
|---|---|---|
| **3×10×4 Bearing** | ID: 3mm, OD: 10mm, Width: 4mm | Front wheel spindle rotation; rear shaft support; eliminates friction at high-load rotating joints |
| **Spacer (Thin)** | Hollow cylinder, small length | Axial positioning of gears and wheels on shaft; prevents lateral play without adding excess mass |
| **Spacer (Thick)** | Hollow cylinder, greater length | Wider axial gaps between components; used where gear or bearing stack-up requires longer standoff |
| **M3 Washer** | M3 standard flat washer | Load distribution under bolt heads and nuts; prevents fastener pull-through in printed parts |

---

## 📁 3D Model File Index

All models were designed in **SolidWorks** and are documented here as PNG render previews. The table below lists every custom-printed or custom-modeled component in the vehicle assembly.

*Quantities listed are for one complete vehicle*

| Component | Preview | Qty | Description |
|---|---|-----|---|
| **Main Chassis** |  | 1 | Primary structural plate with X lightening pockets and integrated mounting zones |
| **Motor Mount** |  | 1 | U-bracket with snap clamp for DC motor, two M3 base holes |
| **Front Wheel Mount** |  | 2 | Wheel upright with bearing bore and square steering pin slot (left/right) |
| **Steer1 — Steering Knuckle** |  | 2 | L-shaped knuckle connecting wheel to chassis pivot (left/right) |
| **Steer2 — Tie Rod** |  | 1 | Flat link bar transmitting servo motion to front knuckles |
| **Steer3 — Left Steering Arm** |  | 1 | Asymmetric arm with Ackermann offset, left side |
| **Steer4 — Right Steering Arm** |  | 1 | Mirror of Steer3 with cylindrical boss for shaft, right side |
| **Front Wheel** |  | 2 | 4-spoke rim with recessed 3×10×4 bearing seat |
| **Rear Wheel** |  | 2 | 4-spoke rim with direct shaft hub, no bearing |
| **Tire** |  | 4 | O-ring torus tire with 3 circumferential grip grooves |
| **0.8M-31T Driven Gear** |  | 1 | 31-tooth 0.8M spur gear with large hub bore for rear shaft |
| **0.8M-31T Motor Gear** |  | 1 | 31-tooth 0.8M spur gear with small bore for motor output shaft |
| **Rear Shaft** |  | 1 | Rear through-axle with differential gear stack and bearing seats |
| **Assembled Differential** |  | 1 | Complete differential sub-assembly reference view |
| **Camera Mount** |  | 1 | Tall vertical bracket with dual adjustment slots for camera height |
| **US-100 Mount** |  | 1 | Box bracket with square sensor cutout and snap-clip retention |
| **Spacer (Thin)** |  | TBD | Short hollow spacer for axial component positioning |
| **Spacer (Thick)** |  | TBD | Tall hollow spacer for wider axial gaps |
| **3×10×4 Bearing** |  | 4+ | Radial ball bearing for front wheel spindles and shaft support |
| **M3 Washer** |  | TBD | Standard flat washer for M3 fasteners |

---

## 🏭 Design & Manufacturing

### 🖥️ CAD Platform
All components were modeled in **SolidWorks** with full parametric feature trees, enabling rapid design iteration and precise dimension control. Assembly files validate fit, clearance, and motion range before any part is printed.

### 🖨️ Printer Platform

All parts were printed on a **Bambu Lab A1 Mini** using **Bambu Studio** as the slicer. The A1 Mini's automatic flow calibration, multi-axis vibration compensation, and fast print speeds (up to 500 mm/s travel) made it possible to iterate quickly between design revisions during development. Dimensional accuracy is high out of the box, which is critical for bearing press-fit seats and gear mesh tolerances.

| Setting | Value |
| --- | --- |
| Printer | Bambu Lab A1 Mini |
| Slicer | Bambu Studio |
| Nozzle diameter | 0.4 mm (standard); 0.25 mm for fine gear details if available |
| Bed surface | Textured PEI plate |
| Print speed | 150–250 mm/s for structural parts; 20–25 mm/s for TPU tires |
| Flow calibration | Auto-calibration run before each material change |

### 🖨️ 3D Printing Strategy
- **Target Material**: PLA for initial prototyping; ABS or PETG for competition parts requiring impact resistance and thermal stability
- **Gear Infill**: 100% for all gear components to prevent tooth deformation under repeated meshing load
- **Structural Parts**: 40–60% infill with rectilinear or gyroid pattern for chassis, mounts, and brackets
- **Bearing Seats**: Printed at 0.08–0.1mm layer height for dimensional accuracy required for press-fit bearing installation
- **Orientation**: Parts oriented to place layer lines perpendicular to primary stress direction, maximizing inter-layer tensile strength where needed

### 🧪 Material Selection per Component

#### Material Overview

| Material | Strengths | Weaknesses | Used for |
| --- | --- | --- | --- |
| **PLA** | High dimensional accuracy, stiff, easy to print, gear-friendly surface | Brittle under impact, low heat resistance (~60 °C), not ideal for repeated flex loads | Gears, wheels, low-stress mounts |
| **PETG** | Impact resistant, tough, good layer adhesion, heat resistant (~80 °C), slight flex prevents crack propagation | Slightly lower stiffness than PLA, strings more during printing, bearing seats need careful calibration | Chassis, steering linkage, motor mount, axle |
| **TPU (95A)** | Flexible, elastic, excellent grip and traction, absorbs vibration | Difficult to print fast, cannot be used for rigid structural parts | Tires only |

#### Per-Component Material Decisions

| Component | Material | Infill | Layer Height | Orientation | Reason |
| --- | --- | --- | --- | --- | --- |
| **Main Chassis** | PETG | 50% Gyroid | 0.15 mm | Flat (XY) | Main structural load path; PETG handles corner impacts and motor vibration without brittle fracture |
| **Motor Mount** | PETG | 60% Rectilinear | 0.15 mm | Upright | Holds motor under continuous torque reaction and vibration; PETG's toughness prevents snap at bolt holes |
| **Front Wheel Mount (×2)** | PETG | 55% Gyroid | 0.10 mm | Upright | Bearing press-fit seat demands tight dimensional tolerance; PETG's toughness handles steering side loads |
| **Steer1 — Knuckle (×2)** | PETG | 55% Rectilinear | 0.15 mm | Flat | Repeated bending stress from steering inputs; PETG prevents crack propagation at the L-bend |
| **Steer2 — Tie Rod** | PETG | 50% Rectilinear | 0.15 mm | Horizontal | Under axial tension and compression every steering cycle; PETG is tougher than PLA for slender rod geometry |
| **Steer3 — Left Arm** | PETG | 55% Rectilinear | 0.15 mm | Flat | Asymmetric arm loaded sideways; PETG tolerates the offset bending moment better than PLA |
| **Steer4 — Right Arm** | PETG | 55% Rectilinear | 0.15 mm | Flat | Same reasoning as Steer3 |
| **0.8M-31T Motor Gear** | PLA | 100% Rectilinear | 0.08 mm | Flat (teeth upright) | Gears need stiff, hard tooth surfaces; PLA provides better mesh accuracy and surface hardness than PETG at this scale |
| **0.8M-31T Driven Gear** | PLA | 100% Rectilinear | 0.08 mm | Flat (teeth upright) | Same as motor gear; 100% infill prevents tooth deformation under repeated meshing load |
| **Rear Shaft** | PETG | 80% Rectilinear | 0.12 mm | Horizontal along shaft axis | Primary drivetrain axle under torsion and bending; PETG's toughness handles shock loads at gear mesh point |
| **Front Wheel (×2)** | PLA | 40% Gyroid | 0.15 mm | Flat | Low mechanical stress — only rotates on bearing; PLA gives good dimensional accuracy for bearing seat |
| **Rear Wheel (×2)** | PLA | 40% Gyroid | 0.15 mm | Flat | Fixed to axle, no bearing; low stress; PLA's stiffness is sufficient |
| **Tire (×4)** | TPU 95A | 100% | 0.20 mm | Flat | Must stretch over rim and provide grip; only flexible material suitable for O-ring tire profile |
| **Camera Mount** | PLA | 35% Gyroid | 0.15 mm | Upright | No significant mechanical load; PLA's rigidity keeps camera angle stable; lighter than PETG |
| **US-100 Mount** | PLA | 35% Gyroid | 0.15 mm | Flat | Sensor holder only — no dynamic load; PLA is sufficient and prints cleanly for snap-clip detail |
| **Spacers (Thin / Thick)** | PLA | 100% | 0.10 mm | Upright | Axial positioning parts; need accurate length; 100% infill prevents compression creep |
| **M3 Washer** | PLA | 100% | 0.10 mm | Flat | Load distribution only; if standard metal washers are available, prefer those |

#### Key Printing Notes

- **Bearing seats** (Front Wheel Mount, Front Wheel, Rear Shaft): print at 0.08–0.10 mm layer height and calibrate flow rate before production runs. A 0.1 mm undersized bore is easier to open than reprinting an oversized one.
- **Gears**: orient so tooth layer lines run perpendicular to the tooth face (teeth pointing up/flat print). Use a 0.4 mm nozzle minimum; 0.25 mm nozzle preferred for 0.8M tooth detail.
- **TPU tires**: print slow (20–25 mm/s), disable retraction or use minimal retraction, and set 100% infill for consistent hardness around the circumference.
- **PETG warp**: use a PEI or glass bed at 70–80 °C; avoid cooling fan for first 2–3 layers. Use brim for thin upright parts (Steer arms, Motor Mount).
- **Symmetric parts** (Steer3/Steer4, Front Wheel Mounts): print left and right in the same batch on the same orientation to ensure geometric symmetry.

### 🔄 Design Iteration Process
1. **Conceptual Layout** — Component placement defined in assembly sketch to lock wheelbase, track width, and sensor positions
2. **Individual Part Modeling** — Each component modeled parametrically with design intent captured in feature names and equations
3. **Assembly Validation** — Full assembly checked for interference, range-of-motion clearances, and cable routing paths
4. **Prototype & Test** — First-print fit check, steering geometry validation, and drivetrain engagement verification
5. **Refinement** — Dimensional corrections, wall thickness optimization, and fastener clearance adjustments applied before production prints

## ✅ Mechanical Validation Tests

| Test | Procedure | Acceptance criteria |
| --- | --- | --- |
| Steering range | Move servo from minimum to maximum command while wheels are lifted. | Linkage reaches both steering directions without binding or wheel/chassis contact. |
| Ackermann behavior | Observe inner/outer wheel angles during left and right steering. | Inner wheel turns more sharply than the outer wheel in both directions. |
| Gear mesh | Spin the drivetrain by hand and then under low PWM. | No skipping, tight spots, or visible gear wobble. |
| Differential action | Hold one rear wheel and rotate the opposite wheel gently. | Differential allows relative wheel motion without excessive friction. |
| Bearing fit | Press bearings into front wheel mounts and rotate wheels. | Bearing stays seated and wheel rotates freely. |
| Sensor mount rigidity | Shake chassis lightly and inspect camera/US-100 brackets. | Sensor angle does not shift under normal handling. |
| Track clearance | Roll vehicle through a practice corner and over cable routing. | Chassis, wires, and mounts do not scrape or catch. |

## ⚠️ Mechanical Risks and Mitigations

| Risk | Mitigation |
| --- | --- |
| Servo linkage backlash | Use short linkage parts, tight fasteners, and repeat `servo_tune.py` after assembly. |
| Gear misalignment | Motor mount fixes shaft center distance and assembly is checked before autonomous runs. |
| Camera vibration | Tall camera mount is bolted directly to the chassis and checked before obstacle testing. |
| Printed part warping | Competition parts should be printed with controlled orientation and higher infill where loads are concentrated. |
| Tire slip | O-ring tires provide a simple repeatable contact patch and can be replaced quickly if worn. |
| Battery/electronics weight shift | Chassis has dedicated electronics zones so mass stays low and centered. |

## 🔁 Repeatability Notes

- Keep the same print orientation for left/right steering parts so geometry stays symmetric.
- Ream or lightly clean bearing holes only when needed; oversized seats reduce repeatability.
- Mark final servo horn position after tuning so the steering center can be rebuilt after maintenance.
- Use the same wheel/tire batch during timed tests to avoid traction differences.
- Route sensor cables away from moving steering links and gears before every run.

---

## 🧩 Assembly Guide

### Phase 1: Rear Drivetrain
1. Press 3×10×4 bearings into rear shaft bearing seats
2. Slide driven gear (`0.8M-31T`) onto rear shaft and secure axially with thin spacers
3. Mount motor onto `motorMount` bracket; press motor gear (`08M-31T_Motor`) onto motor output shaft
4. Bolt `motorMount` assembly to chassis — verify gear mesh engagement and backlash
5. Install rear wheels onto shaft ends, securing with washers and locking fasteners

### Phase 2: Front Steering System
1. Press 3×10×4 bearings into `Front_Wheel_Mount` bearing bores
2. Install `Steer1` knuckles into chassis front pivot points
3. Connect `Steer3` and `Steer4` arms to servo output horn and knuckle pins respectively
4. Thread `Steer2` tie rod between knuckle connection points; adjust length for zero toe-in at center
5. Install front wheels onto spindles through bearing bores; verify free rotation with no lateral play

### Phase 3: Sensor & Electronics Integration
1. Bolt `CamMount` to designated chassis standoff holes; slide camera module into slots, set height, tighten
2. Snap US-100 sensor into `US100_Mount` bracket; bolt bracket to front chassis face
3. Install PCB/controller into electronics bay using chassis integrated standoffs
4. Route all wiring through chassis cable channels away from moving drivetrain components

---

## ✅ Validation Checklist

- **Steering Range**: Confirm full left-to-right servo travel translates to expected wheel deflection angles without binding
- **Differential Function**: With rear wheels off ground, verify each rear wheel can rotate independently while the other is held
- **Gear Mesh**: No noise or skip at full motor speed; correct backlash (0.1–0.2mm) between 0.8M gears
- **Bearing Seating**: All bearings fully seated, no axial float, smooth rotation under light finger pressure
- **Sensor Alignment**: Camera FOV centered on track ahead; US-100 sensors aimed level and perpendicular to travel direction
- **Fastener Torque**: All M3 bolts confirmed snug; locking elements (nyloc or threadlocker) applied to high-vibration joints

---

For electrical systems documentation: [Schemes Documentation](../schemes/README.md)  
For software implementation and algorithms: [Software Documentation](../src/README.md)  
For performance demonstrations: [Video Documentation](../video/README.md)  
For additional resources and photos: [Other Documentation](../other/README.md)

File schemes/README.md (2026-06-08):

# Electronics Schemes

This directory documents the electronics used in the WRO 2026 Future Engineers robot. It includes the complete wiring scheme and a bill of materials for the main controller, sensors, motor driver, power system, drive motor, and steering servo.

## Main Wiring Scheme

Complete electronics wiring scheme

The wiring scheme is built around a Raspberry Pi Pico 2 W H controller. The Pico controls the motor driver, steering servo, two US-100 ultrasonic sensors, MPU6050 IMU, and TCS34725 color sensor. The ESP32-CAM works as a separate vision module and sends camera detections to the Pico over UART.

## Complete Bill of Materials (BOM)

| Component | Image | Quantity | Type | Description |
| --- | --- | ---: | --- | --- |
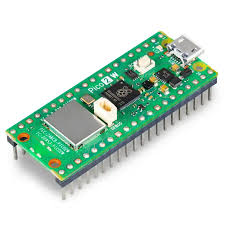
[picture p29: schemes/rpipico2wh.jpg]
Raspberry Pi Pico 2 W H
| Raspberry Pi Pico 2 W H |  | 1 | Main microcontroller | Runs the MicroPython control code for steering, motor control, sensor reading, open round, and obstacle round behavior. |
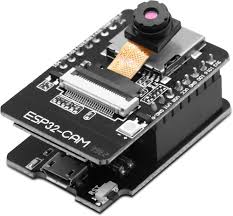
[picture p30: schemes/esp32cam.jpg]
ESP32-CAM
| ESP32-CAM |  | 1 | Camera module | Detects red and green obstacles and sends compact UART messages to the Pico. |
| TB6612FNG | TB6612FNG motor driver | 1 | Motor driver | Drives the 6 V DC motor using PWM and direction signals from the Pico. |
| 6 V micro DC motor | 6 V micro DC motor | 1 | Drive motor | Provides propulsion for the vehicle through the drivetrain. |
| HD-1440A servo | HD-1440A servo | 1 | Steering servo | Controls the steering mechanism and receives PWM commands from the Pico. |
| US-100 ultrasonic sensor | US-100 ultrasonic sensor | 3 | Distance sensor | Measures distance for wall detection, corner detection, and safety checks. Sensor 1: GPIO 10/11. Sensor 2: GPIO 12/13. Sensor 3: GPIO 2/3. |
| MPU9250 | MPU9250 IMU | 1 | IMU / gyro sensor | Provides yaw-rate data for heading correction, 90-degree turns, and recovery after obstacle passing. |
| TCS34725 | TCS34725 color sensor | 1 | Color sensor | Reference/backup color sensing module for future color-based improvements. |
| LM2596 / RT3505 buck converter | Buck converter module | 2 | Voltage regulator | Steps battery voltage down for electronics and actuator rails. Output voltage must be checked before connecting modules. |
| 2S 450 mAh LiPo battery | 2S 450 mAh LiPo battery | 1 | Battery | Main robot power source. Feeds the regulator stage through the main switch. |
| On/off switch | On/off switch | 1 | Power switch | Enables safe manual power control for the robot. |

## Cable and Connection Specifications

All voltage values are nominal. Current values are worst-case peaks unless otherwise noted.

### 1. Main Power Source and Regulator Inputs

The 2S LiPo battery output (7.4 V nominal, 8.4 V fully charged) feeds three destinations through the main on/off switch.

| From | To | Voltage | Peak Current | Notes |
| --- | --- | ---: | ---: | --- |
| 2S LiPo (+) | On/off switch (input) | 7.4–8.4 V | 2.5 A | System peak: motor under load + servo moving + camera streaming |
| On/off switch (output) | Buck converter 1 (IN+) | 7.4–8.4 V | 0.6 A | Logic rail input |
| On/off switch (output) | Buck converter 2 (IN+) | 7.4–8.4 V | 1.0 A | Servo rail input |
| On/off switch (output) | TB6612FNG VM | 7.4–8.4 V | 1.0 A | Direct battery voltage to motor power pin — motor must tolerate 2S voltage |
| 2S LiPo (−) | Common GND bus | 0 V | — | Shared ground for all modules |

The TB6612FNG VM pin receives direct battery voltage. The DC motor therefore runs at 7.4–8.4 V. Motor current varies between 300 mA and 1 A depending on PWM duty cycle and mechanical load.

### 2. Buck Converter Outputs

Both buck converters step the battery voltage down to 5 V efficiently.

#### Buck Converter 1 — System Rail (5 V output)

| From | To | Voltage | Current | Notes |
| --- | --- | ---: | ---: | --- |
| Buck 1 (OUT+) | Pico 2 W H VBUS | 5.0 V | 50–100 mA | Pico draws more during heavy computation |
| Buck 1 (OUT+) | ESP32-CAM 5V | 5.0 V | 100–400 mA | ~100 mA idle; up to 400 mA when Wi-Fi and flash are active |
| Buck 1 (OUT+) | TB6612FNG VCC | 5.0 V | 1–5 mA | Logic supply only; motor power comes directly from battery |
| Buck 1 (OUT−) | Common GND bus | 0 V | — | |

Total Buck 1 output load: approximately **400–500 mA**.

#### Buck Converter 2 — Servo Rail (5 V or 6 V output)

| From | To | Voltage | Current | Notes |
| --- | --- | ---: | ---: | --- |
| Buck 2 (OUT+) | HD-1440A servo power (red wire) | 5.0 V (or 6.0 V) | 10–1000 mA | ~10 mA idle; up to 1 A instantaneous peak under mechanical load or sudden movement |
| Buck 2 (OUT−) | Common GND bus | 0 V | — | |

Set Buck 2 to **5 V** as default. Switching to **6 V** provides higher torque and speed if the servo and wiring support it.

### 3. Sensors Powered from Pico 3.3 V

The Pico 2 W H converts its 5 V VBUS input to a clean 3.3 V rail through its onboard regulator and feeds all sensors.

| From | To | Voltage | Current | Notes |
| --- | --- | ---: | ---: | --- |
| Pico 3V3 (OUT) | TCS34725 VCC | 3.3 V | ~5 mA | Includes onboard LED current |
| Pico 3V3 (OUT) | MPU6050 VCC | 3.3 V | ~4 mA | Gyro and accelerometer combined |
| Pico GND | All sensor GNDs | 0 V | — | Common reference for all I2C and UART signals |

Total Pico 3.3 V rail load: approximately **9–10 mA** (well within the 300 mA regulator limit).

The three US-100 sensors are powered from **Buck 1 (5 V)**, not the Pico 3.3 V rail.

| From | To | Voltage | Current | Notes |
| --- | --- | ---: | ---: | --- |
| Buck 1 (OUT+) | US-100 #1 VCC | 5.0 V | ~8 mA | Sensor 1 — GPIO 10/11 |
| Buck 1 (OUT+) | US-100 #2 VCC | 5.0 V | ~8 mA | Sensor 2 — GPIO 12/13 |
| Buck 1 (OUT+) | US-100 #3 VCC | 5.0 V | ~8 mA | Sensor 3 — GPIO 2/3 |

### 4. Signal and Data Lines

| From | To | Signal Voltage | Notes |
| --- | --- | ---: | --- |
| Pico GPIO 14 (PWM) | HD-1440A servo signal (yellow wire) | 3.3 V | 50 Hz PWM, 1–2 ms pulse width |
| Pico GPIO 16 (PWM) | TB6612FNG PWMA | 3.3 V | Motor speed control |
| Pico GPIO 17 | TB6612FNG AIN2 | 3.3 V | Motor direction |
| Pico GPIO 18 | TB6612FNG AIN1 | 3.3 V | Motor direction |
| Pico GPIO 19 | TB6612FNG STBY | 3.3 V | Must be HIGH to enable motor output |
| Pico GPIO 4 (SDA) | MPU6050 SDA / TCS34725 SDA | 3.3 V | Shared I2C data bus; 4.7 kΩ pull-up to 3.3 V recommended |
| Pico GPIO 5 (SCL) | MPU6050 SCL / TCS34725 SCL | 3.3 V | Shared I2C clock bus; 4.7 kΩ pull-up to 3.3 V recommended |
| Pico GPIO 10 (TRIG) | US-100 #1 TRIG | 3.3 V | 10 µs trigger pulse — Sensor 1; US-100 TRIG accepts 3.3 V |
| US-100 #1 ECHO | 1 kΩ + 2 kΩ divider → Pico GPIO 11 | 5 V → 3.3 V | ECHO output is 5 V; resistor divider steps to 3.3 V for Pico. ~1.6 mA line current |
| Pico GPIO 12 (TRIG) | US-100 #2 TRIG | 3.3 V | 10 µs trigger pulse — Sensor 2; US-100 TRIG accepts 3.3 V |
| US-100 #2 ECHO | 1 kΩ + 2 kΩ divider → Pico GPIO 13 | 5 V → 3.3 V | ECHO output is 5 V; resistor divider steps to 3.3 V for Pico. ~1.6 mA line current |
| Pico GPIO 2 (TRIG) | US-100 #3 TRIG | 3.3 V | 10 µs trigger pulse — Sensor 3; US-100 TRIG accepts 3.3 V |
| US-100 #3 ECHO | 1 kΩ + 2 kΩ divider → Pico GPIO 3 | 5 V → 3.3 V | ECHO output is 5 V; resistor divider steps to 3.3 V for Pico. ~1.6 mA line current |
| ESP32-CAM TX | 1 kΩ + 2 kΩ divider → Pico GPIO 1 (UART RX) | 5 V → 3.3 V | ESP32-CAM TX is 5 V logic. The resistor divider steps it to 3.3 V for the Pico RX pin. Line current ~1.6 mA. |
| Pico GPIO 0 (UART TX) | ESP32-CAM RX | 3.3 V | Pico TX at 3.3 V is within ESP32-CAM input range; no level shifting needed |

### Current Budget Summary

| Rail | Consumers | Typical | Peak |
| --- | --- | ---: | ---: |
| Battery direct — TB6612FNG VM | DC motor | 300 mA | 1.0 A |
| Buck 1 — 5 V logic | Pico (100 mA) + ESP32-CAM (400 mA) + TB6612FNG VCC (5 mA) + US-100 ×3 (24 mA) | 274 mA | 529 mA |
| Buck 2 — servo rail | HD-1440A servo | 10 mA | 1.0 A |
| Pico 3.3 V out | MPU6050 (4 mA) + TCS34725 (5 mA) | 9 mA | 10 mA |
| **Battery total** | **All rails** | **~560 mA** | **~2.5 A** |

The 2S LiPo battery voltage (7.4–8.4 V) is passed directly to the TB6612FNG motor driver to maximize motor efficiency. Logic and servo voltages are regulated down to 5 V by LM2596 buck converters for stable, repeatable behavior across the battery discharge curve.

Before first power-on, measure Buck 1 output and set it to **5.0 V**, then measure Buck 2 output and set it to **5.0 V** (or **6.0 V** for the servo). Do not connect any board until both outputs are confirmed.

## Signal and Power Summary

| Connection group | Modules | Notes |
| --- | --- | --- |
| Motor control | Pico 2 W H -> TB6612FNG -> DC motor | PWM controls speed, direction pins control motor direction. |
| Steering | Pico 2 W H -> HD-1440A servo | Servo limits are tuned in `src/servo_tune.py`. |
| Distance sensing | Pico 2 W H -> US-100 #1 (GPIO 10/11) + US-100 #2 (GPIO 12/13) | Two sensors used by `src/openround.py` and `src/obstacleround.py` for wall/corner detection from different directions. |
| Gyro heading | Pico 2 W H -> MPU9250 | I2C gyro data is used for yaw estimation and turn completion. |
| Camera UART | ESP32-CAM -> Pico 2 W H | The camera sends `RED`, `GREEN`, or `NONE` messages for obstacle logic. |
| Color sensing | Pico 2 W H -> TCS34725 | Reserved as an extra color sensing module. |
| Power regulation | LiPo -> switch -> buck converters -> modules | All grounds must be common. Regulator outputs must be measured before testing. |

## Power Budget and Rail Plan

The robot separates high-current actuator loads from logic/sensor loads so motor noise does not reset the controller or corrupt sensor data.

| Rail | Loads | Reason |
| --- | --- | --- |
| Battery input | Main switch, buck converters | Keeps the battery path short and easy to disconnect during testing. |
| Motor/servo rail | TB6612FNG motor supply and steering servo supply | Handles current spikes from acceleration, braking, and fast steering changes. |
| Logic rail | Pico 2 W H, ESP32-CAM, MPU6050, TCS34725, US-100 ×2 logic | Keeps controller and sensor voltage stable during motor load changes. |
| Common ground | All modules | Required for PWM, UART, I2C, trigger/echo, and camera signals to share the same reference. |

Expected current risks:

- The ESP32-CAM can draw high current during Wi-Fi/camera startup, so it should not share a weak rail with the Pico without enough regulator margin.
- The steering servo can create voltage dips when held against mechanical load.
- The drive motor can inject noise into the supply through the TB6612FNG if wiring is long or loose.

The chosen architecture uses buck converters because the battery voltage is higher than the safe voltage for logic boards and because a regulated rail gives repeatable sensor behavior across the battery discharge curve.

## Sensor Placement Reasoning

| Sensor | Placement reason | Trade-off |
| --- | --- | --- |
| ESP32-CAM | Mounted high enough to see colored obstacles before the vehicle reaches them. | Higher mounting improves view, but increases vibration sensitivity. |
| US-100 #1 (GPIO 10/11) | Faces forward to detect walls and corners early enough for a 90-degree turn. | Very close readings can be noisy, so software filters unrealistic distances. |
| US-100 #2 (GPIO 12/13) | Mounted to cover a second direction (side or rear) for expanded spatial awareness. | Both sensors share the same filtering logic; trigger pulses are staggered to avoid crosstalk. |
| MPU9250 | Placed near the chassis center to reduce rotational measurement error from vibration. | Needs startup calibration while the robot is still. |
| TCS34725 | Kept as a reference/backup color sensor for future color validation. | Not part of the current primary obstacle algorithm. |

## Calibration and Fault Management

| Check | Method | Failure response |
| --- | --- | --- |
| Voltage rails | Measure buck converter outputs with a multimeter before connecting boards. | Do not connect electronics until output voltage is corrected. |
| I2C sensors | Confirm MPU9250/TCS34725 addresses are detected. | Stop the run and inspect SDA/SCL, power, and ground wiring. |
| UART camera | Verify `RED`, `GREEN`, and `NONE` messages before autonomous runs. | Use `src/camera_uart_blink.py` for isolated UART testing. |
| Ultrasonic distance | Compare US-100 readings against known distances. | Reject readings below the configured minimum and inspect trigger/echo wiring. |
| Motor polarity | Test with wheels lifted from the ground. | Swap motor leads or invert direction logic before track testing. |
| Servo direction | Run `src/servo_tune.py`. | Adjust servo reverse/settings before autonomous code is used. |

## Safety Checklist

- Check every buck converter output with a multimeter before connecting electronics.
- Keep the Pico, ESP32-CAM, motor driver, sensors, and power system on a common ground.
- Confirm UART TX/RX wiring direction between the ESP32-CAM and Pico.
- Confirm the US-100 echo signal is safe for Pico input voltage.
- Test the servo direction before running autonomous code.
- Test motor direction with wheels lifted from the ground.
- Secure the LiPo battery physically before driving.
- Use the switch to cut power quickly during bench tests.

## Software Mapping

| Software file | Electronics used |
| --- | --- |
| `src/camera.cpp` | ESP32-CAM |
| `src/camera_uart_blink.py` | ESP32-CAM UART output and Pico onboard LED |
| `src/openround.py` | Pico, servo, TB6612FNG, DC motor, US-100 ×2 (GPIO 10/11 + 12/13), MPU6050 |
| `src/obstacleround.py` | Pico, ESP32-CAM, servo, TB6612FNG, DC motor, US-100 ×2 (GPIO 10/11 + 12/13), MPU6050 |
| `src/servo_tune.py` | Pico, steering servo, MPU6050 |

This folder should be updated whenever the electronics layout, wiring, power system, or sensor placement changes.

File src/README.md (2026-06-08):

# WRO 2026 Future Engineers Software Documentation

This folder contains the robot source code for Team CYBERRCORE's WRO 2026 Future Engineers vehicle. The software is split between an ESP32-CAM vision module written in Arduino C++ and MicroPython control utilities for open round, obstacle round, sensor, UART, and servo tuning. This documentation was last updated on June 4, 2026.

## Software Architecture Overview

The current software is organized around two main roles:

- **ESP32-CAM vision module**: Captures low-resolution RGB565 frames, detects red and green objects, and sends compact serial messages.
- **MicroPython vehicle controller utilities**: Drive the steering servo, motor driver, ultrasonic distance sensor, and MPU9250 gyro for open-round navigation, obstacle-round navigation, and calibration.
- **UART communication**: Vision output uses newline-terminated messages at 115200 baud, allowing another board to react to camera detections.

The system keeps the runtime logic simple and deterministic. The camera module only reports color and horizontal position, while the vehicle control code handles movement, turning, and tuning.

```text
ESP32-CAM camera.cpp
        |
        | Serial: COLOR,x,count
        v
MicroPython UART reader
        |
        v
LED debug / vehicle control integration

MicroPython openround.py
        |
        +-- TB6612FNG motor driver
        +-- Steering servo
        +-- US-100 ultrasonic distance sensor
        +-- MPU9250 gyro over I2C

MicroPython obstacleround.py
        |
        +-- ESP32-CAM UART color obstacle data
        +-- Gyro heading correction
        +-- US-100 corner detection
        +-- Lap and corner counting
        +-- Run log output
```

## Programming Environment and Tools

### ESP32-CAM Vision Module

- **Language**: Arduino C++
- **Target board**: AI Thinker ESP32-CAM
- **Main library**: `esp_camera`
- **Camera format**: RGB565
- **Frame size**: QQVGA, 160x120
- **Output protocol**: Serial at 115200 baud

### MicroPython Controller Utilities

- **Language**: MicroPython
- **Hardware APIs**: `machine.Pin`, `machine.PWM`, `machine.I2C`, `machine.UART`
- **Actuators**: Steering servo and TB6612FNG motor driver
- **Sensors**: MPU9250 gyro and US-100 ultrasonic distance sensor
- **Debugging**: Console output and onboard LED blink feedback

## Core Software Components

| File | Language | Purpose |
| --- | --- | --- |
| [`camera.cpp`](camera.cpp) | Arduino C++ | ESP32-CAM color detection for red and green objects |
| [`camera_uart_blink.py`](camera_uart_blink.py) | MicroPython | UART receiver test that blinks LED on camera color messages |
| [`openround.py`](openround.py) | MicroPython | Open-round drive logic with gyro-assisted 90-degree corner turns |
| [`obstacleround.py`](obstacleround.py) | MicroPython | Obstacle-round logic combining camera color tracking, gyro recovery, corner turns, and lap counting |
| [`servo_tune.py`](servo_tune.py) | MicroPython | Servo center, direction, and PID steering tuning utility |

## Vision System

The ESP32-CAM code reads RGB565 frames at 160x120 resolution and scans the lower part of the image. Scanning starts at `ROI_Y_START = 30` and skips pixels with `STEP_X = 2` and `STEP_Y = 2` to reduce processing time.

### Color Detection Strategy

The camera converts each RGB565 pixel into RGB888 values and checks threshold rules:

- **Red**: high red channel, low green and blue channels, and red dominance over both other channels.
- **Green**: high green channel, limited red and blue channels, and green dominance over both other channels.
- **Minimum area**: detections must exceed `RED_MIN_AREA` or `GREEN_MIN_AREA`.

When both colors are visible, red is prioritized if it has at least as much detected area as green.

### Camera Output Format

The camera writes one line per frame:

```text
RED,<center_x>,<pixel_count>
GREEN,<center_x>,<pixel_count>
NONE
```

This compact format is easy to parse on a second microcontroller and avoids sending full images over UART.

## Open Round Navigation

`openround.py` implements a simple open-round strategy for repeated corner turns:

1. Center the servo and calibrate the gyro.
2. Drive straight with PID steering toward `target_yaw`.
3. Read front distance with the US-100 sensor.
4. If an obstacle or wall is closer than `TURN_DISTANCE_CM`, enter turn mode.
5. Hold full steering left or right until the gyro reports about 90 degrees of yaw change.
6. Reset yaw, briefly ignore corner detection, and continue.
7. After `STOP_AFTER_TURNS = 16`, drive straight briefly and stop.

### State Machine

Open Round State Machine

## Obstacle Round Navigation

`obstacleround.py` extends the base driving system for the WRO obstacle round. It combines camera color detections, gyro heading control, ultrasonic corner detection, and a multi-state obstacle passing routine.

### Obstacle Strategy

The ESP32-CAM reports colored obstacle data over UART. The obstacle-round script uses this information to choose a passing line:

- **Red obstacle**: keep the red object on the left side of the camera view so the robot passes on its right.
- **Green obstacle**: keep the green object on the right side of the camera view so the robot passes on its left.
- **No obstacle visible**: continue gyro-assisted forward driving and use ultrasonic distance to detect corners.

The target camera positions are:

| Obstacle | Target camera x | Intended pass side |
| --- | --- | --- |
| Red | `RED_TARGET_X = 48` | Pass on the right |
| Green | `GREEN_TARGET_X = 112` | Pass on the left |

### Obstacle State Machine

Obstacle Round State Machine

### Lap and Corner Counting

The obstacle-round script tracks `corner_count` and `lap_count`. After every four corners, one lap is counted. The robot stops when `REQUIRED_LAPS = 3` is reached.

### Logging

`obstacleround.py` can write runtime data to `run_log.txt`. The log records mode changes, calibration events, snapshots, corner turns, lap completions, and unexpected exceptions. This helps diagnose behavior after a physical run without relying only on live console output.

### Edge Cases and Mitigations

| Risk | Mitigation in code |
| --- | --- |
| False ultrasonic readings at very short range | Distances below `MIN_VALID_DISTANCE_CM` are rejected and close-stop logic requires repeated close readings. |
| Same wall counted twice after a turn | `TURN_IGNORE_AFTER_TURN_MS` blocks immediate corner re-triggering. |
| Corner triggered while avoiding an obstacle | `TURN_IGNORE_AFTER_COLOR_MS` delays corner detection after color tracking starts. |
| Camera briefly loses the obstacle | `LOST_COLOR` keeps a short bias based on the last known color instead of instantly returning to normal driving. |
| Two obstacles appear close together | `chain_active` extends pass duration and increases pass bias for chained red/green patterns. |
| Gyro drift after major maneuvers | Yaw and PID state are reset after turns and recovery events. |
| UART buffer noise or partial messages | The buffer is bounded and lines are parsed only after newline termination. |

## Control System

The steering controller uses a basic PID loop:

```python
error = target_yaw - yaw
integral += error * dt
derivative = (error - last_error) / dt
output = (KP * error) + (KI * integral) + (KD * derivative)
```

The correction is applied around `SERVO_CENTER`. If `SERVO_REVERSE` is enabled, positive correction moves the servo in the opposite direction. This makes the same control code usable when the steering linkage orientation changes.

Current tuning values:

| Parameter | Value |
| --- | --- |
| `SERVO_MIN` | 30 |
| `SERVO_CENTER` | 65 |
| `SERVO_MAX` | 100 |
| `KP` | 1.8 |
| `KI` | 0.00 |
| `KD` | 0.25 |
| `MOTOR_SPEED_STRAIGHT` | 30 |
| `MOTOR_SPEED_TURN` | 50 |

Obstacle-round tuning values:

| Parameter | Value |
| --- | --- |
| `SERVO_MIN` | 50 |
| `SERVO_CENTER` | 65 |
| `SERVO_MAX` | 80 |
| `MOTOR_SPEED_FOLLOW` | 65 |
| `MOTOR_SPEED_COLOR` | 48 |
| `MOTOR_SPEED_PASS` | 42 |
| `MOTOR_SPEED_TURN` | 57 |
| `TURN_DISTANCE_CM` | 45 |
| `STOP_DISTANCE_CM` | 6 |
| `KP_HEADING` | 2.4 |
| `KD_HEADING` | 0.35 |

## Engineering Decisions and Trade-offs

| Decision | Why it was chosen | Trade-off |
| --- | --- | --- |
| Separate ESP32-CAM vision module | Keeps camera processing off the main Pico controller and gives a simple UART interface. | Requires a second board and stable serial wiring. |
| RGB thresholding instead of ML | Runs fast on ESP32-CAM and is easy to tune on the track. | Sensitive to lighting, so threshold calibration is needed. |
| Gyro-based turn completion | More repeatable than timing-only turns. | Requires startup calibration and drift handling. |
| US-100 for corner detection | Simple, cheap, and direct front-wall measurement. | Needs filtering for close-range noise. |
| State machine control | Easy to debug and explain during judging. | More states require careful transition timing. |
| Logging to `run_log.txt` | Allows post-run diagnosis without watching serial output live. | Writes are limited by MicroPython filesystem reliability and should not be too frequent. |

## Test Plan and Acceptance Criteria

| Test | Procedure | Pass criteria |
| --- | --- | --- |
| Camera color detection | Show red, green, and no object to ESP32-CAM. | Serial output changes between `RED`, `GREEN`, and `NONE` within one frame loop. |
| UART receiver | Run `camera_uart_blink.py` with camera connected. | Red gives one blink, green gives two blinks, repeated same color does not spam blinks. |
| Servo direction | Run `servo_tune.py` while the robot is lifted. | Center, left, right, and PID correction directions match the steering geometry. |
| Gyro calibration | Keep robot still during startup. | Yaw remains near zero while stationary and changes consistently during rotation. |
| Ultrasonic distance | Place a wall at known distances. | Readings are stable and impossible close readings are filtered. |
| Open round | Run `openround.py` on a practice track. | Robot completes repeated 90-degree turns without double-counting the same wall. |
| Obstacle round | Run `obstacleround.py` with red/green obstacles. | Red is passed on the correct side, green is passed on the correct side, and heading recovers after each pass. |

## UART Test Utility

`camera_uart_blink.py` validates the camera serial output without needing the full vehicle logic. It reads UART lines and blinks the onboard LED:

- `RED` -> one blink
- `GREEN` -> two blinks
- `NONE` -> re-arms the detector

The script avoids repeated blinking while the same color remains visible. This makes it easier to confirm whether the camera is detecting new objects or continuously seeing the same object.

## Servo Tuning Utility

`servo_tune.py` helps tune steering limits and center position:

1. Center the servo.
2. Calibrate the MPU9250 gyro.
3. Hold straight using the PID controller for `PID_START_TIME_MS`.
4. Move to `TEST_SERVO_ANGLE`.
5. Keep the servo at that angle for mechanical inspection.

This is useful for checking whether `SERVO_MIN`, `SERVO_CENTER`, `SERVO_MAX`, and `SERVO_REVERSE` match the physical steering geometry.

## Hardware Pin Summary

### MicroPython Controller

| Signal | Pin |
| --- | --- |
| Servo PWM | 14 |
| Motor PWMA | 16 |
| Motor AIN2 | 17 |
| Motor AIN1 | 18 |
| Motor STBY | 19 |
| I2C SDA | 4 |
| I2C SCL | 5 |
| Ultrasonic TRIG | 10 |
| Ultrasonic ECHO | 11 |
| Camera UART TX | 0 |
| Camera UART RX | 1 |

### AI Thinker ESP32-CAM

The ESP32-CAM pin mapping follows the standard AI Thinker camera layout in `camera.cpp`, including XCLK on GPIO0, SCCB on GPIO26/GPIO27, and RGB data pins on GPIO5, GPIO18, GPIO19, GPIO21, GPIO34, GPIO35, GPIO36, and GPIO39.

## Testing and Validation

Recommended validation order:

1. Upload `camera.cpp` to the ESP32-CAM and confirm `ESP32_CAM_READY`.
2. Place red and green objects in view and confirm serial messages.
3. Run `camera_uart_blink.py` on the MicroPython controller and verify LED blink behavior.
4. Run `servo_tune.py` to confirm steering limits and PID direction.
5. Run `openround.py` on blocks or a safe test area to verify motor direction.
6. Test the full open-round behavior on the WRO track at low speed first.
7. Run `obstacleround.py` after camera UART output, steering direction, gyro calibration, and ultrasonic distance readings are confirmed.

## Deployment Instructions

### ESP32-CAM

1. Open `camera.cpp` in the Arduino IDE or compatible ESP32 build environment.
2. Select the AI Thinker ESP32-CAM board profile.
3. Build and upload the firmware.
4. Open the serial monitor at 115200 baud.
5. Confirm that `ESP32_CAM_READY` appears.

### MicroPython Controller

Copy the required `.py` file to the MicroPython board filesystem:

```bash
cp openround.py /path/to/micropython-board/
cp obstacleround.py /path/to/micropython-board/
cp servo_tune.py /path/to/micropython-board/
cp camera_uart_blink.py /path/to/micropython-board/
```

Rename the active script to `main.py` if automatic startup is needed.

## Photo Documentation

The source documentation includes development photos to show the physical robot setup, wiring work, and track testing process.

### Open-Round Track Test

Open-round track testing with the robot inside a cardboard practice field

This photo shows the robot being tested in a handmade open-round practice field. The cardboard walls were used as a quick simulation of the WRO Future Engineers track boundaries while tuning the ultrasonic corner detection, gyro-based turn counting, and steering behavior.

### Bench Build and Wiring

Robot bench wiring and development setup

This photo shows the robot during bench development with the controller, wiring, laptop, and test environment visible. It documents the practical debugging setup used while working on the camera, UART, servo, and drive-control code.

Recommended additional documentation photos:

- Full robot wiring layout
- ESP32-CAM mount and field of view
- Servo linkage and center position
- MPU9250 and US-100 placement
- Close-up of the drive motor and steering assembly

## Engineering Notes

- The camera intentionally uses a small frame size and pixel skipping for faster detection.
- The gyro is calibrated at startup, so the robot must stay still during calibration.
- `TURN_IGNORE_AFTER_TURN_MS` prevents the same wall from being counted as a new corner immediately after turning.
- The obstacle-round script ignores corner triggers briefly after color detection so obstacle passing does not accidentally start a corner turn.
- `run_log.txt` is generated on the MicroPython board during obstacle-round runs when logging is enabled.
- The code favors simple thresholds and state machines so behavior can be tuned quickly during physical testing.

## Future Improvements

- Align the ESP32-CAM output format across open-round tests and obstacle-round mode.
- Save tuning constants in a separate configuration file.
- Add separate test scripts for motor, ultrasonic sensor, gyro, and UART.
- Add lighting-condition calibration notes for red and green thresholds.
- Add photos and short videos linked from the documentation folders.

---

This source documentation is intended to make the WRO Future Engineers software understandable, testable, and easy to tune during robot development.

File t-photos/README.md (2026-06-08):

# Team Photos

Two photos of Team CYBERRCORE — the people behind the robot.

---

### Official Photo — `normal.jpeg`

Team CYBERRCORE Official Photo

---

### Fun Photo — `fun.jpeg`

Team CYBERRCORE Fun Photo

---

We are a three-person team from Turkey, competing in the WRO 2026 Future Engineers category. We design, build, and program our robot entirely from scratch — from CAD modeling in SolidWorks to writing the control software on the ESP32.

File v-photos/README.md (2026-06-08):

# Vehicle Photos

Six orthographic photos of the CYBERRCORE prototype, taken from front, rear, top, bottom, left and right. The robot is currently in active development — wiring runs on a breadboard platform and cable routing is not yet finalized. Photos reflect the real build state, not a polished final assembly.

---

### `front.jpeg`

Front View

The front face of the robot. The **ESP32-CAM** sits on its custom 3D printed bracket at center, camera lens aimed forward for track and obstacle detection. Directly below the chassis nose, the **US-100 ultrasonic sensor** (green PCB with dual transducers) is mounted flush for forward distance measurement. Both front wheels use blue hub rims with pressed **3×10×4 bearings** and rubber O-ring tires.

---

### `rear_view.jpeg`

Rear View

The rear of the robot exposes the drivetrain exit point: the **0.8M 31T spur gear** on the rear axle is clearly visible at center. The **brushed DC drive motor** sits behind it in its U-bracket mount. The large black **toggle power switch** is accessible from the rear for easy field use. The elevated breadboard platform with the motor driver and control modules sits on top, and the **red JST battery connector** hangs free on the right side.

---

### `top_view.jpeg`

Top View

Bird's-eye view showing the full electronics layout. The **red breadboard** on the left carries all prototype circuitry — motor driver, sensor breakout modules, and interconnects. The **ESP32-CAM** is visible toward the front-left. Bamboo/wooden support columns raise the electronics layer above the chassis deck. The dense jumper wire harness is typical of the development stage and will be replaced with consolidated wiring for competition.

---

### `bottom_view.jpeg`

Bottom View

The underside reveals the full mechanical layout. On the front-left, the **Ackermann steering linkage** is visible — servo arm, tie rod, and wheel knuckles working together so both front wheels turn toward the correct center point. The **steering servo** sits just inboard of the front axle. On the rear-right, the **0.8M spur gear pair** (1:1 ratio) transfers motor torque to the rear through-axle. A small **blue sensor module** (IMU or color sensor) is mounted flat to the chassis underside. The X-pattern lightening pockets in the chassis plate are visible throughout.

---

### `left_view.jpeg`

Left View

Full left-side profile. The height hierarchy of the robot is clear: flat chassis base at the bottom, electronics platform raised on support columns in the middle, and the ESP32-CAM tower at the top. The **blue front wheel** (steered, bearing hub) and **gray rear wheel** (driven, direct hub) show the intentional design difference between the two axles. The power switch and battery connector are accessible without turning the robot over.

---

### `right_view.jpeg`

Right View

The right side gives the clearest view of the **rear gear train** — motor, pinion gear, and axle driven gear are all visible here. The contrast between the blue front wheel hub and the plain gray rear wheel hub confirms the front uses a pressed bearing for free rotation while the rear hub is fixed to the axle. Wiring from the upper platform routes down through the chassis to the motor and servo along this side.

---

## Development Notes

These photos show a working prototype, not the final competition robot. Key things that will change before competition:

- Breadboard and jumper wires → consolidated wiring or custom PCB
- Exposed cable routing → managed harness with strain relief
- Support column structure → integrated chassis uprights if space permits

For mechanical part details: [Models Documentation](../models/README.md)  
For electrical schematics: [Schemes Documentation](../schemes/README.md)  
For software: [Software Documentation](../src/README.md)

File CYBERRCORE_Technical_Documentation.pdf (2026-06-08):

# WRO 2026

# Future Engineers

# Team CYBERRCORE


Full Robot Assembly — Isometric View

## TECHNICAL ENGINEERING DOCUMENTATION

## TECHNICAL ENGINEERING DOCUMENTATION

Document version: June 2026 | Confidential — WRO Competition Use Only

# Table of Contents

### 1 System Overview

3

### 2 Mechanical Design

4
2.1 Main Chassis

4
2.2 Steering System

5
2.3 Rear Drivetrain & Differential

6
2.4 Wheel & Tire System

7
2.5 Sensor & Electronics Mounts

8

### 3 Electronics & Wiring

9
3.1 Bill of Materials

9
3.2 Cable & Connection Specifications | 10
3.3 Power Budget | 12
4 Software Architecture | 13
4.1 Vision System (ESP32
-CAM) | 13
4.2 Open Round Navigation | 14
4.3 Obstacle Round Navigation | 15
4.4 Control System (PID) | 16
5 Vehicle Photos | 17
6 Validation & Testing | 19
7 Engineering Decisions | 20

# 1 System Overview

Team CYBERRCORE's WRO 2026 Future Engineers robot is a fully autonomous wheeled vehicle designed for the open-round and obstacle-round competition formats. The system integrates a Raspberry Pi Pico 2 W H main controller with an ESP32-CAM vision module, a TB6612FNG brushed DC motor driver, a HD-1440A steering servo, US-100 ultrasonic distance sensor, and MPU6050 IMU — all powered from a 2S 450 mAh LiPo battery through dual LM2596 buck converter rails.
All mechanical components were custom-designed in SolidWorks and 3D-printed. The chassis uses a flat-plate architecture with X-pattern lightening cutouts, Ackermann front steering linkage, and a 1:1 spur-gear differential rear drivetrain. The software stack is split between Arduino C++ firmware on the ESP32-CAM for color detection and MicroPython scripts on the Pico for navigation, motor control, and sensor fusion.
Subsystem | Technology | Role
Main Controller | Raspberry Pi Pico 2 W H | MicroPython navigation, PID steering, sensor fusion
Vision Module | ESP32-CAM (Arduino C++) | RGB565 color detection, UART obstacle reporting
Motor Driver | TB6612FNG | PWM drive control for brushed DC motor
Drive Motor | 6 V Micro DC Motor | Rear wheel propulsion via 1:1 spur gear
Steering | HD-1440A Servo | Ackermann front wheel steering
Distance Sensing | US-100 Ultrasonic | Wall detection, corner trigger, safety stop
IMU / Gyro | MPU6050 | Yaw estimation, 90° turn completion, heading recovery
Color Sensor | TCS34725 | Backup / future color validation
Power Source | 2S 450 mAh 40C LiPo | Main battery — 7.4 V nominal
Regulation | 2× LM2596 Buck Converter | 5 V logic rail + 5/6 V servo rail
Chassis / Structure | SolidWorks + FDM 3D Print | All mechanical parts custom-designed and printed

# 2 Mechanical Design

The mechanical platform is designed around structural rigidity with strategic weight reduction. A flat-plate chassis architecture keeps the center of gravity low, simplifies assembly, and provides dedicated mounting zones for every subsystem. All parts were modeled parametrically in SolidWorks and 3D-printed in PLA for prototyping with PETG/ABS targeted for competition.

## 2.1 Main Chassis

The primary structural plate features X-pattern lightening pockets that remove mass where structurally unnecessary while preserving load paths. Integrated standoff columns allow direct PCB mounting without separate hardware. Distinct zones are pre-allocated for motor mount, servo, differential, and sensor brackets.


Main chassis — X-pattern lightening pockets and integrated standoff columns
Feature | Detail
Architecture | Single-level flat plate — low CG for stability at speed
Lightening Cutouts | X-pattern triangular pocket geometry
Standoff Columns | Molded-in posts for direct PCB and cover mounting
Subsystem Zones | Dedicated areas for motor, servo, differential, sensor brackets
Perimeter Rail | Continuous edge flange for external bracket attachment
Print Settings | 40–60% infill, gyroid pattern, layer lines ⊥ to primary stress

## 2.2 Steering System — 4-Part Ackermann Linkage

The front steering uses a four-component Ackermann-compliant linkage ensuring both front wheels track toward a common turn center during cornering. The asymmetric offset geometry of the steering arms ensures the inner wheel turns through a greater angle than the outer wheel, eliminating tire scrub.


Steer1 — Steering Knuckle: L-shaped bracket connecting wheel spindle to chassis pivot


Steer2 — Tie Rod: flat bar transmitting servo motion to front knuckles
Part | Role | Key Feature
Steer1 — Knuckle | Connects wheel spindle to chassis upright | L-shape; upper hole for servo pin, lower for chassis pivot
Steer2 — Tie Rod | Transmits servo motion to wheel knuckles | Equal-diameter holes at each end, backlash-free length
Steer3 — Left Arm | Translates servo rotation to wheel angle | Asymmetric boss; compensates Ackermann geometry (left)
Steer4 — Right Arm | Mirror function for right wheel | Cylindrical boss for shaft engagement; mirrored to Steer3

## 2.3 Rear Drivetrain & Differential

The rear drivetrain uses a 1:1 spur-gear pair (31T–31T, 0.8 module) to transfer motor torque to a through-axle supported by 3×10×4 bearings. A differential allows independent rear wheel rotation during turns, preventing inside-wheel scrub and improving corner repeatability.


Assembled differential — rear shaft, gear stack, and bearing assembly
Parameter | Value | Justification
Gear module | 0.8M | Compact pitch suited for small-scale precision drivetrains
Tooth count | 31T : 31T | 1:1 ratio — preserves full motor RPM
Drive ratio | 1:1 | Prioritises speed; torque sufficient for vehicle mass
Bearing type | 3×10×4 radial ball | Reduces friction; consistent over repeated laps
Differential | Custom printed | Allows independent rear wheel speeds in corners

## 2.4 Wheel & Tire System

Front and rear wheels have distinct designs to match their functional roles. O-ring style tires press onto the outer rim flange, providing simple replacement and consistent rolling contact patch.

Aspect | Front Wheel | Rear Wheel
Hub Type | Recessed bearing seat (press-fit 3×10×4) | Direct shaft hub — no bearing
Spoke Pattern | 4 spokes with intermediate web | 4 solid spokes, lighter
Function | Free rotation around fixed spindle | Fixed to axle shaft, driven rotationally
Tire Fit | O-ring press-fit over rim flange | O-ring press-fit over rim flange

Tire profile: O-ring torus with three parallel circumferential grip grooves. Material: flexible rubber/TPU. Advantages: tool-free replacement, consistent geometry batch-to-batch.

## 2.5 Sensor & Electronics Mounts


Camera Mount — tall vertical bracket with dual height-adjustment slots


US-100 Mount — box bracket with square sensor cutout and snap-clip retention
Mount | Key Features
Camera Mount (CamMount) | Tall vertical bracket; 2 vertical adjustment slots for height fine-tuning; angled forward lean for near-field obstacle detection; 2 M3 base holes
US-100 Mount (US100_Mount) | Box-form bracket; square cutout sized to US-100 body; side snap-tab — no fasteners; 4 corner mounting holes; compact to minimise aerodynamic interference
Motor Mount (motorMount) | U-bracket wrapping motor on 3 sides; snap-clip for tool-free removal; 2 M3 base holes; gear alignment built into mount geometry

# 3 Electronics & Wiring


Complete electronics wiring scheme

## 3.1 Bill of Materials

Component | Qty | Type | Description
Raspberry Pi Pico 2 W H | 1 | Main MCU | MicroPython — steering, motor, sensors, navigation
ESP32-CAM | 1 | Camera module | RGB565 color detection; UART obstacle reporting to Pico
TB6612FNG | 1 | Motor driver | PWM + direction control for brushed DC motor
6 V Micro DC Motor | 1 | Drive motor | Rear wheel propulsion via spur gear drivetrain
HD-1440A Servo | 1 | Steering servo | PWM-controlled Ackermann front steering
US-100 Ultrasonic | 1 | Distance sensor | Front wall / corner detection; safety stop
MPU6050 | 1 | IMU / Gyro | Yaw estimation for PID heading and 90° turns
TCS34725 | 1 | Color sensor | Backup / future color validation module
LM2596 / RT3505 Buck | 2 | Voltage regulator | Buck 1: 5 V logic rail | Buck 2: 5–6 V servo rail
2S 450 mAh 40C LiPo | 1 | Battery | Main power — 7.4 V nominal, 8.4 V full charge
On/Off Switch | 1 | Power switch | Manual power cut for safe bench and field use
3×10×4 Bearing | 4+ | Hardware | Front spindles and rear shaft support
M3 Fasteners / Washers | TBD | Hardware | Chassis, mount, and bracket assembly

## 3.2 Cable & Connection Specifications

### 3.2.1 Main Power Source & Regulator Inputs

The 2S LiPo battery (7.4 V nominal, 8.4 V fully charged) feeds three destinations through the main on/off switch. The TB6612FNG VM pin receives direct battery voltage — the DC motor therefore runs at 7.4–8.4 V for maximum efficiency.

From | To | Voltage | Peak Current | Notes
2S LiPo (+) | On/off switch (IN) | 7.4–8.4 V | 2.5 A | Full-load peak across all rails
Switch (OUT) | Buck 1 (IN+) | 7.4–8.4 V | 0.6 A | Logic rail input
Switch (OUT) | Buck 2 (IN+) | 7.4–8.4 V | 1.0 A | Servo rail input
Switch (OUT) | TB6612FNG VM | 7.4–8.4 V | 1.0 A | Direct battery → motor power pin
2S LiPo (−) | Common GND bus | 0 V | — | Shared ground for all modules

### 3.2.2 Buck Converter 1 — Logic Rail (5 V)

From | To | Voltage | Current | Notes
Buck 1 (OUT+) | Pico 2 W H VBUS | 5.0 V | 50–100 mA | Powers Pico onboard 3.3 V regulator
Buck 1 (OUT+) | ESP32-CAM 5V | 5.0 V | 100–400 mA | ~100 mA idle; up to 400 mA Wi-Fi + flash
Buck 1 (OUT+) | TB6612FNG VCC | 5.0 V | 1–5 mA | Logic supply only; motor from battery directly

Total Buck 1 output load: approximately 400–500 mA.

### 3.2.3 Buck Converter 2 — Servo Rail (5 V or 6 V)

From | To | Voltage | Current | Notes
Buck 2 (OUT+) | HD-1440A servo (red) | 5.0 V (opt. 6.0 V) | 10–1000 mA | ~10 mA idle; up to 1 A peak under load or sudden movement

Set Buck 2 to 5 V default. Switch to 6 V for higher torque/speed if wiring supports it.

### 3.2.4 Pico 3.3 V Sensor Rail

The Pico converts its 5 V VBUS to a clean 3.3 V rail via its onboard regulator and feeds all sensors.

From | To | Voltage | Current | Notes
Pico 3V3 OUT | TCS34725 VCC | 3.3 V | ~5 mA | Includes onboard LED
Pico 3V3 OUT | MPU6050 VCC | 3.3 V | ~4 mA | Gyro + accelerometer combined
Pico 3V3 OUT | US-100 VCC | 3.3 V | ~20 mA | Peak during measurement pulse
Pico GND | All sensor GNDs | 0 V | — | Common reference

Total Pico 3.3 V load: ~30–40 mA — well within the 300 mA regulator limit.

### 3.2.5 Signal & Data Lines

From | To | Voltage | Notes
Pico GPIO 14 (PWM) | HD-1440A servo signal (yellow) | 3.3 V | 50 Hz PWM, 1–2 ms pulse
Pico GPIO 16 (PWM) | TB6612FNG PWMA | 3.3 V | Motor speed control
Pico GPIO 17 | TB6612FNG AIN2 | 3.3 V | Motor direction
Pico GPIO 18 | TB6612FNG AIN1 | 3.3 V | Motor direction
Pico GPIO 19 | TB6612FNG STBY | 3.3 V | Must be HIGH to enable motor output
Pico GPIO 4 (SDA) | MPU6050 SDA / TCS34725 SDA | 3.3 V | Shared I2C data; 4.7 kΩ pull-up
Pico GPIO 5 (SCL) | MPU6050 SCL / TCS34725 SCL | 3.3 V | Shared I2C clock; 4.7 kΩ pull-up
Pico GPIO 10 (TRIG) | US-100 TRIG | 3.3 V | 10 µs trigger pulse
Pico GPIO 11 (ECHO) | US-100 ECHO | 3.3 V | US-100 echo is 3.3 V compatible
ESP32-CAM TX | 1kΩ+2kΩ divider → Pico GPIO 1 RX | 5V → 3.3V | Level-shift required; ~1.6 mA line current
Pico GPIO 0 TX | ESP32-CAM RX | 3.3 V | 3.3 V within ESP32-CAM range; no shifting needed

## 3.3 Power Budget

Rail | Consumers | Typical | Peak
Battery direct → TB6612FNG VM | DC Motor | 300 mA | 1.0 A
Buck 1 — 5 V logic | Pico (100 mA) + ESP32-CAM (400 mA) + TB6612FNG VCC (5 mA) | 250 mA | 505 mA
Buck 2 — servo rail | HD-1440A Servo | 10 mA | 1.0 A
Pico 3.3 V out | MPU6050 (4 mA) + TCS34725 (5 mA) + US-100 (20 mA) | 29 mA | 40 mA
BATTERY TOTAL | All rails combined | ~590 mA | ~2.5 A

Measure Buck 1 output → set to 5.0 V. Measure Buck 2 output → set to 5.0 V (or 6.0 V for servo). Do not connect any board until both outputs are confirmed with a multimeter.

# 4 Software Architecture

The software is split between two microcontrollers. The ESP32-CAM runs Arduino C++ firmware that captures RGB565 frames and reports color detections over UART at 115200 baud. The Raspberry Pi Pico 2 W H runs MicroPython scripts that handle motor control, steering PID, sensor fusion, navigation state machines, and lap counting.

File | Platform | Purpose
camera.cpp | ESP32-CAM / Arduino C++ | RGB565 color detection for red and green obstacles; UART output
camera_uart_blink.py | Pico / MicroPython | UART receiver test — blinks LED on camera messages
openround.py | Pico / MicroPython | Open-round drive logic with gyro-assisted 90° corner turns
obstacleround.py | Pico / MicroPython | Obstacle-round: camera tracking, gyro recovery, lap counting
servo_tune.py | Pico / MicroPython | Servo center, direction, and PID steering tuning utility

## 4.1 Vision System (ESP32-CAM)

The ESP32-CAM captures QQVGA (160×120) RGB565 frames and scans the lower region (ROI_Y_START = 30) with a 2×2 pixel step. Each pixel is converted to RGB888 and tested against threshold rules for red and green. When both colors appear, red is prioritised if its detected area is at least equal to green.
UART output format (one line per frame):

RED,<center_x>,<pixel_count> GREEN,<center_x>,<pixel_count>
NONE
Color | Detection Rule
Red | High red channel; low green and blue; red dominates both other channels
Green | High green channel; limited red and blue; green dominates both other channels
Priority | Red prioritised when red area ≥ green area
Min area | Must exceed RED_MIN_AREA or GREEN_MIN_AREA to register

## 4.2 Open Round Navigation

openround.py implements a deterministic state machine for repeated 90° corner turns. A PID loop corrects heading using MPU6050 yaw; the US-100 triggers turn entry when the front wall is closer than TURN_DISTANCE_CM. After STOP_AFTER_TURNS = 16 corners the robot stops.


Open Round State Machine
State | Condition to leave | Next state
STRAIGHT | distance < TURN_DISTANCE_CM | TURN
TURN | turned angle ≥ TURN_ANGLE − TURN_TOLERANCE | STRAIGHT or FINAL_STRAIGHT
FINAL_STRAIGHT | final timer complete | STOPPED
STOPPED | — | —

## 4.3 Obstacle Round Navigation

obstacleround.py extends the base driver for the WRO obstacle round. It combines camera UART detections with gyro heading control, ultrasonic corner detection, and a multi-state obstacle passing routine. The robot tracks corner_count and lap_count; it stops after REQUIRED_LAPS = 4.

Obstacle | Target camera x | Pass side
Red | RED_TARGET_X = 48 | Pass on the right
Green | GREEN_TARGET_X = 112 | Pass on the left
None visible | — | Gyro-assisted forward drive


Obstacle Round State Machine
Risk | Mitigation
False ultrasonic readings at close range | Distances below MIN_VALID_DISTANCE_CM rejected
Same wall counted twice after turn | TURN_IGNORE_AFTER_TURN_MS blocks immediate re-trigger
Corner trigger during obstacle avoidance | TURN_IGNORE_AFTER_COLOR_MS delays corner detection
Camera briefly loses obstacle | LOST_COLOR keeps short bias from last known color
Two obstacles close together | chain_active extends pass duration and increases bias
Gyro drift after manoeuvres | Yaw and PID state reset after turns and recovery events
UART buffer noise / partial messages | Buffer bounded; lines parsed only after newline termination

## 4.4 Control System (PID)

Steering uses a discrete PID loop:

error | = target_yaw - yaw
integral | += error * dt
derivative = (error - last_error) / dt
output | = (KP * error) + (KI * integral) + (KD * derivative)
Parameter | Open Round | Obstacle Round
SERVO_MIN | 30 | 50
SERVO_CENTER | 65 | 65
SERVO_MAX | 100 | 80
KP | 1.8 | 2.4 (KP_HEADING)
KI | 0.00 | —
KD | 0.25 | 0.35 (KD_HEADING)
MOTOR_SPEED_STRAIGHT | 30 | 65 (FOLLOW)
MOTOR_SPEED_TURN | 50 | 57
TURN_DISTANCE_CM | — | 45
STOP_DISTANCE_CM | — | 6

# 5 Vehicle Photos

The following photos show the current prototype build. Wiring runs on a breadboard platform and cable routing is not yet finalised. These images reflect the real build state used during development and testing.

## Front View


ESP32-CAM on custom bracket at centre; US-100 ultrasonic below chassis nose; blue front wheels with pressed 3×10×4 bearings and O-ring tires.

## Rear View


0.8M 31T spur gear visible on rear axle; brushed DC motor in U-bracket; toggle power switch at rear; red JST battery connector.

## Top View

Red breadboard with all prototype circuitry; ESP32-CAM front-left; bamboo support columns elevating electronics layer above chassis.

## Bottom View


Ackermann steering linkage visible front-left; servo inboard of front axle; 0.8M spur gear pair rear-right; X-pattern lightening pockets throughout.

## Left View

Height hierarchy: flat chassis → electronics platform → ESP32-CAM tower. Blue steered front wheel and grey driven rear wheel.

## Right View

Clearest view of rear gear train: motor, pinion, and axle driven gear. Front bearing hub vs rear direct shaft hub contrast visible.

# 6 Validation & Testing

## 6.1 Mechanical Validation

Test | Procedure | Pass Criteria
Steering range | Servo min→max while wheels lifted | Full travel without binding or wheel/chassis contact
Ackermann behaviour | Observe inner/outer wheel angles | Inner wheel turns more sharply than outer in both directions
Gear mesh | Hand-spin, then low PWM | No skipping, tight spots, or visible gear wobble
Differential action | Hold one wheel, rotate opposite | Allows relative motion without excess friction
Bearing fit | Press bearing, spin wheel | Bearing seated; wheel rotates freely with no lateral play
Sensor mount rigidity | Light shake of chassis | Camera/US-100 angle does not shift
Track clearance | Roll through practice corner | No chassis, wire, or mount scraping

## 6.2 Electronics Validation

Check | Method | Failure Response
Voltage rails | Multimeter on buck outputs before connecting boards | Do not connect until output corrected
I2C sensors | Confirm MPU6050/TCS34725 addresses detected | Inspect SDA/SCL, power, ground
UART camera | Verify RED/GREEN/NONE messages | Use camera_uart_blink.py for isolated test
Ultrasonic | Compare readings against known distances | Reject below minimum; inspect TRIG/ECHO wiring
Motor polarity | Test with wheels lifted | Swap leads or invert direction logic
Servo direction | Run servo_tune.py | Adjust reverse/settings before autonomous code

## 6.3 Software / Track Validation

Test | Procedure | Pass Criteria
Camera detection | Show red, green, and no object to ESP32-CAM | Serial output changes between RED, GREEN, NONE within one frame
UART receiver | Run camera_uart_blink.py with camera connected | Red → 1 blink, green → 2 blinks; no spam on sustained colour
Open round | Run openround.py on practice track | Completes 16 corners without double-counting walls
Obstacle round | Run obstacleround.py with red/green obstacles | Red passed on correct side; green passed on correct side; heading recovers
Lap counting | Full 4-lap run | Robot stops after exactly 4 laps

# 7 Engineering Decisions & Trade-offs

Decision | Why chosen | Trade-off
Separate ESP32-CAM vision module | Offloads camera processing from main Pico; simple UART interface | Requires second board and stable serial wiring; level-shifting for 5→3.3 V
TB6612FNG VM fed directly from battery (7.4–8.4 V) | Maximises motor efficiency; no buck converter losses in motor power path | Motor must tolerate 2S voltage; speed varies slightly across discharge curve
Dual separate buck converters | Isolates motor/servo transients from logic rail; servo gets dedicated current headroom | Two regulators to set and verify; more wiring
1:1 spur gear drivetrain | Preserves full motor RPM for straight-line speed | Lower torque multiplication; relies on low vehicle mass
Differential rear axle | Prevents inside-wheel scrub in corners; improves repeatability | More printed parts; alignment checks required
RGB thresholding instead of ML | Runs at full frame rate on ESP32-CAM; easy to tune on track | Sensitive to lighting; threshold calibration needed per venue
Gyro-based 90° turn completion | More repeatable than timing-only turns | Requires startup calibration; drift handling after major manoeuvres
US-100 for corner detection | Simple, direct front-wall measurement; cheap and reliable | Needs filtering for close-range noise readings
State machine control | Easy to debug and explain during judging | More states require careful transition timing
Flat-plate chassis with X-pattern cutouts | Low CG; easy to add mounting points; weight reduction without sacrificing stiffness | Less inherent rigidity than a box frame; layer orientation matters for print strength
Ackermann steering linkage | Eliminates tire scrub in corners; improves repeatability | 4 parts to assemble and align; geometry depends on print accuracy
O-ring tires | Simple replacement; consistent geometry batch-to-batch; no gluing | Limited traction tuning vs custom moulded compounds
run_log.txt logging | Allows post-run diagnosis without live serial monitoring | MicroPython filesystem writes can be slow; log rate must not block control loop

This document covers the complete engineering evidence for Team CYBERRCORE's WRO 2026 Future Engineers robot — mechanical design, electronics architecture, wiring specifications, software algorithms, and validation procedures.
WRO 2026 — Team CYBERRCORE | June 2026

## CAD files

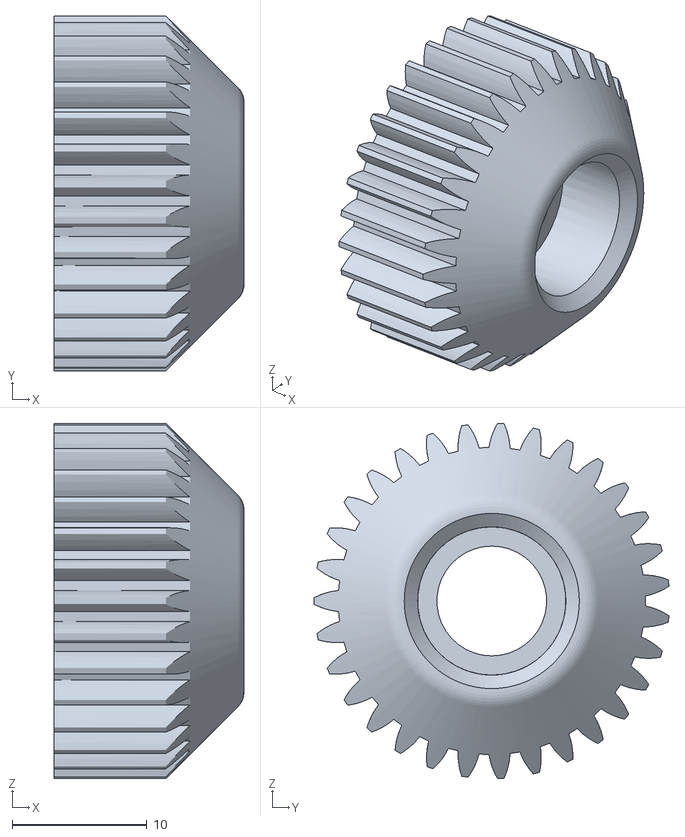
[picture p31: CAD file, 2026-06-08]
models/STL/ShaftGear.STL
14.1 x 26.4 x 26.4

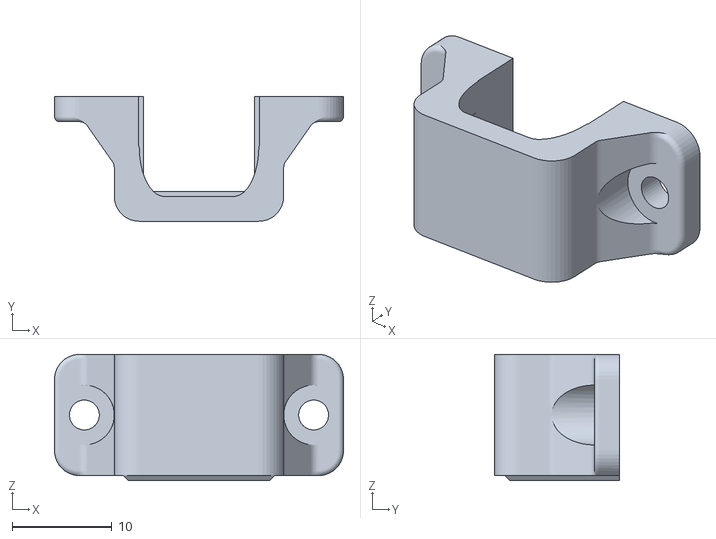
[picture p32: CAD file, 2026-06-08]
models/STL/motorMount.STL
29.0 x 12.5 x 12.6

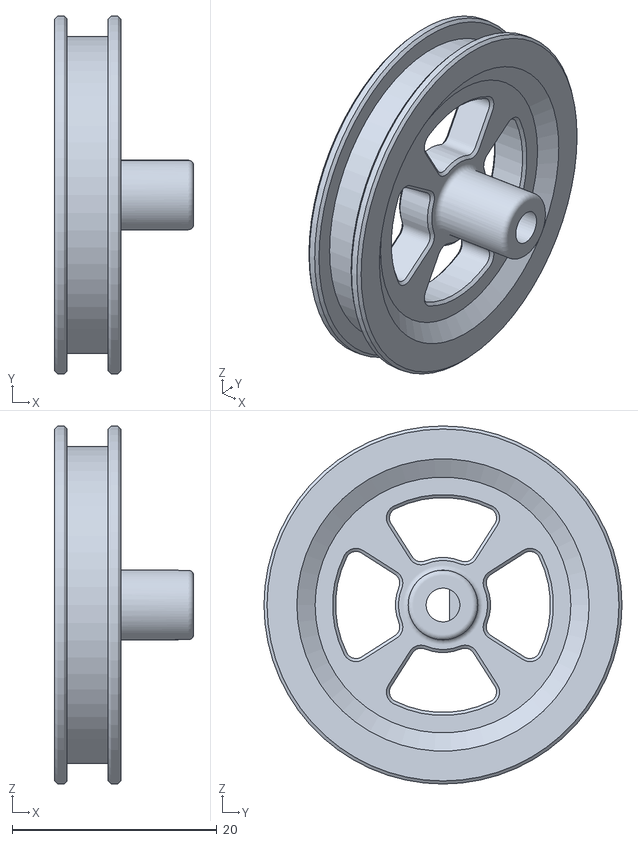
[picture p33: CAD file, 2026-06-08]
models/STL/WheelBack_2-adet.STL
13.6 x 35.0 x 35.0

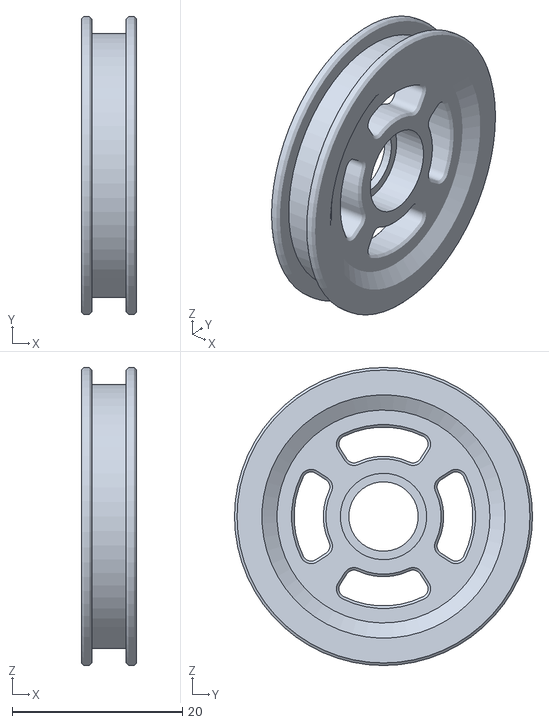
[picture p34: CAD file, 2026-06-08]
models/STL/WheelFront_2-adet.STL
6.50 x 35.0 x 35.0

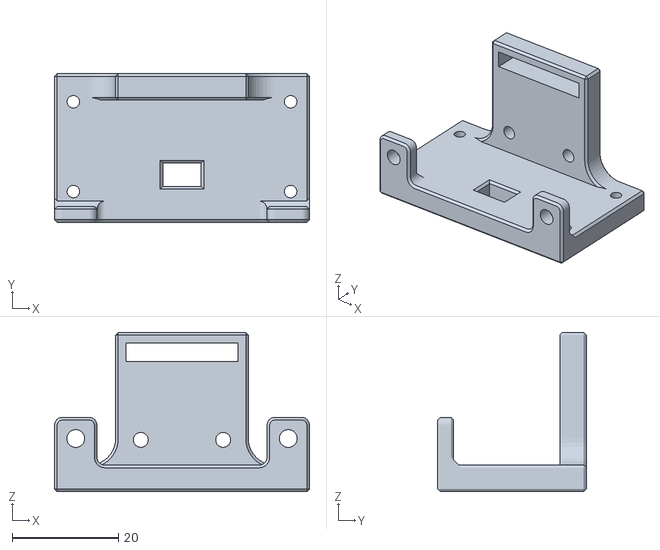
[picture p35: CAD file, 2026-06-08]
models/STL/US100_Mount.STL
48.0 x 28.0 x 30.0

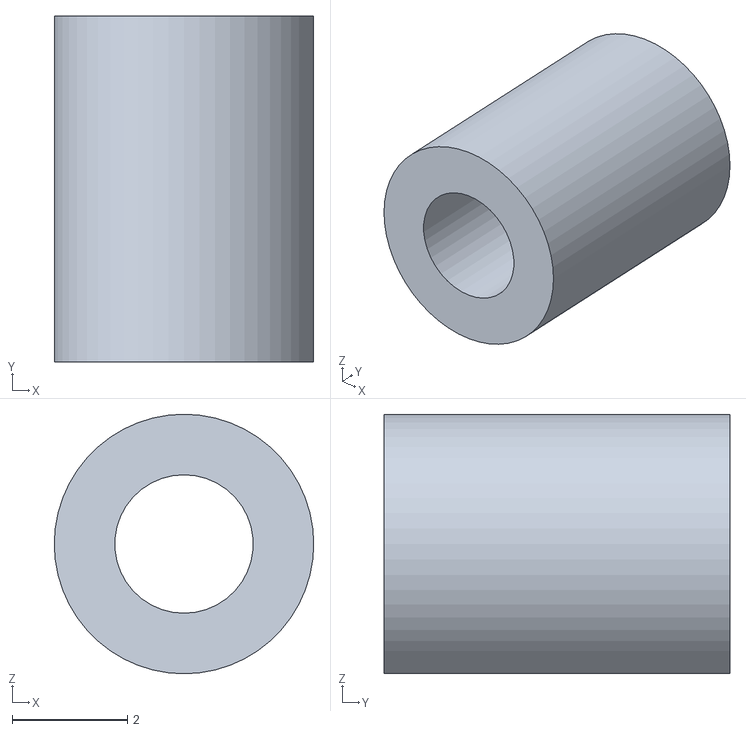
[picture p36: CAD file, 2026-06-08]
models/STL/Spacer2_4-adet.STL
4.50 x 6.00 x 4.50

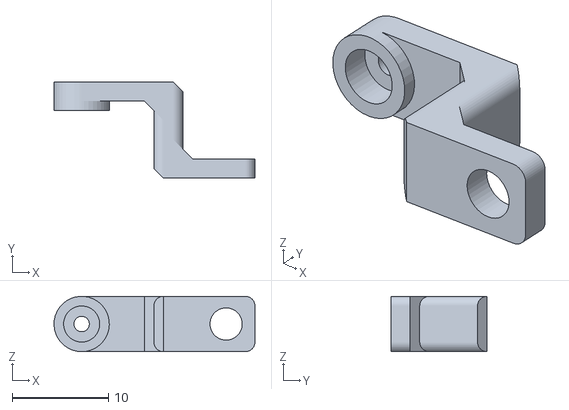
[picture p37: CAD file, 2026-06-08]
models/STL/Steer1.STL
20.9 x 10.0 x 5.75

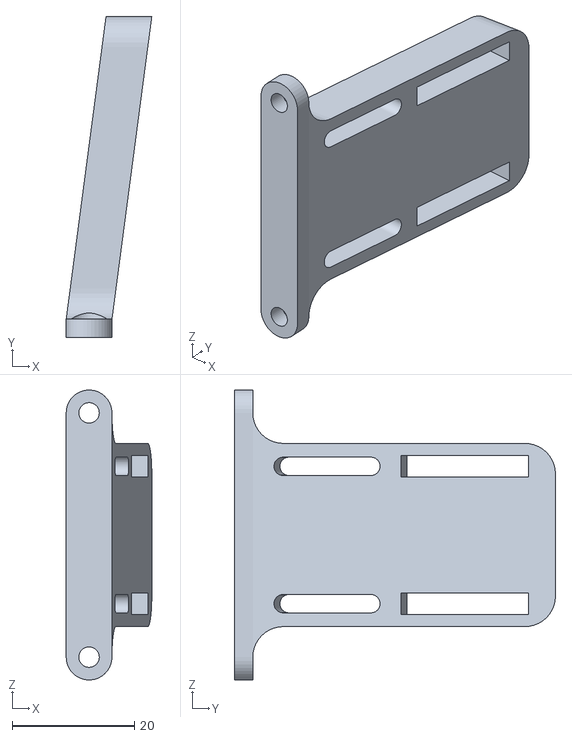
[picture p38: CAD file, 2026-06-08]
models/STL/CamMount.STL
14.0 x 52.6 x 47.5

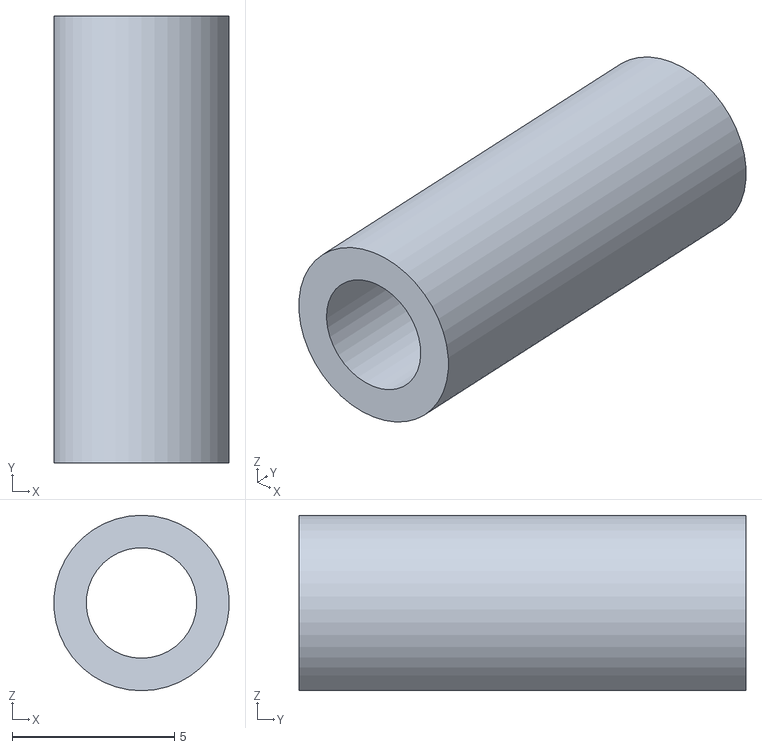
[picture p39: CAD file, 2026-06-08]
models/STL/Spacer_2-adet.STL
5.38 x 13.8 x 5.40

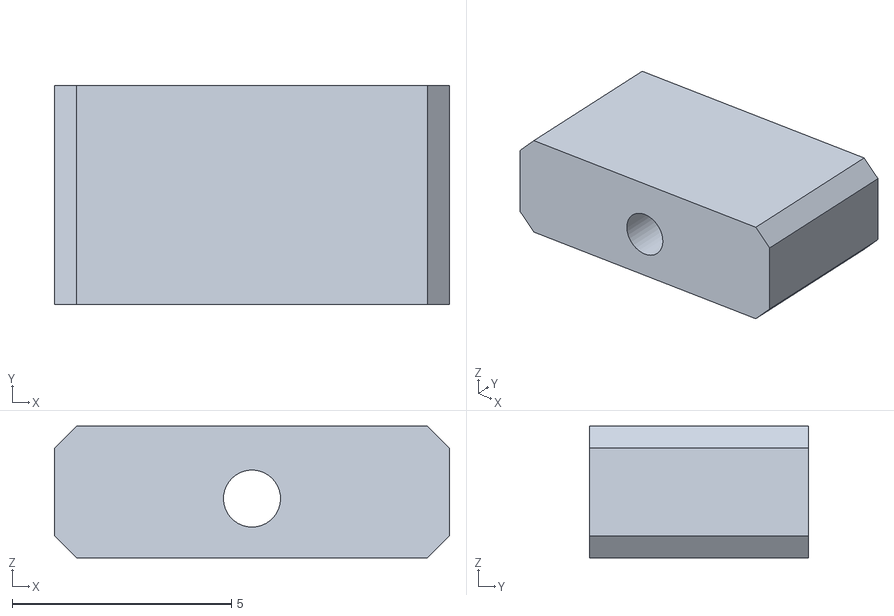
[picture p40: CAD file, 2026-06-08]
models/STL/ServoMount_2-adet.STL
9.00 x 5.00 x 3.00

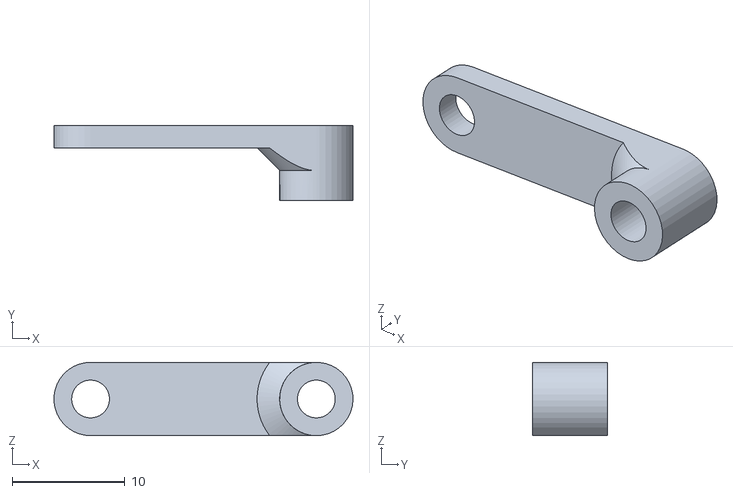
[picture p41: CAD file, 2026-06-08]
models/STL/Steer4.STL
26.5 x 6.65 x 6.50

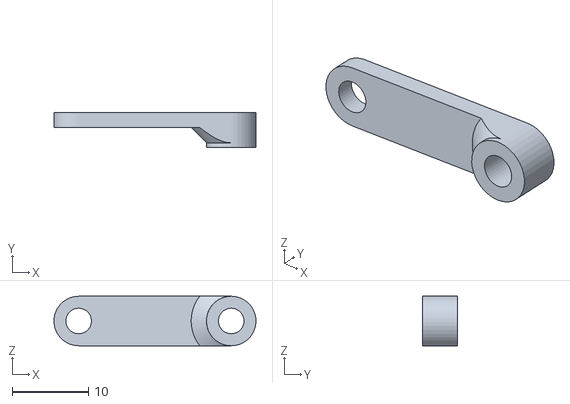
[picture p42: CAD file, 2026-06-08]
models/STL/Steer3.STL
26.5 x 4.65 x 6.50

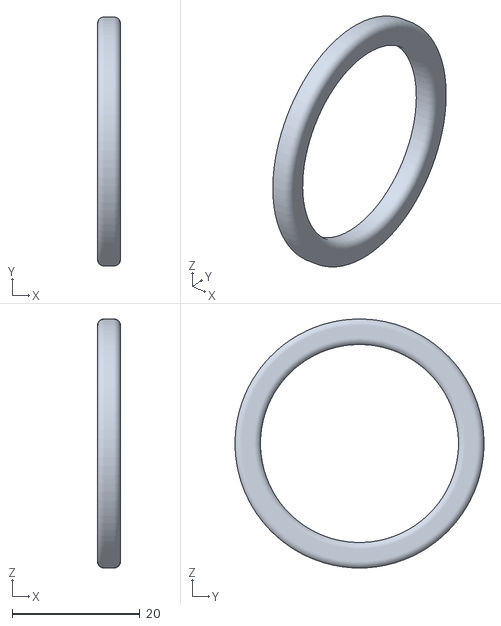
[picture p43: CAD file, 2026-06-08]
models/STL/Tire_4-adet.STL
3.60 x 39.0 x 39.0

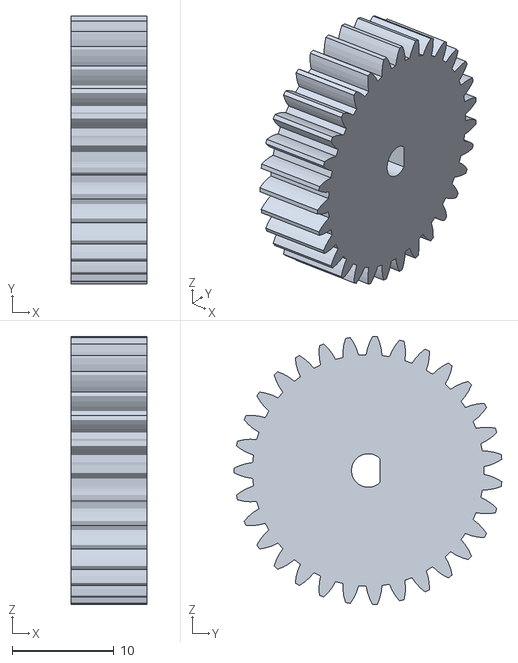
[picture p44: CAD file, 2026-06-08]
models/STL/MotorGear.STL
7.50 x 26.4 x 26.4

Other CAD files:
models/STL/FrontWheelMount_2-adet.STL
models/STL/Steer2_2-adet.STL
models/STL/AnaGövde.STL

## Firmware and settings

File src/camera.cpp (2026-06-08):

#include <Arduino.h>
#include "esp_camera.h"

// =====================================================
// AI Thinker ESP32-CAM pins
// =====================================================

#define PWDN_GPIO_NUM     32
#define RESET_GPIO_NUM    -1
#define XCLK_GPIO_NUM      0
#define SIOD_GPIO_NUM     26
#define SIOC_GPIO_NUM     27

#define Y9_GPIO_NUM       35
#define Y8_GPIO_NUM       34
#define Y7_GPIO_NUM       39
#define Y6_GPIO_NUM       36
#define Y5_GPIO_NUM       21
#define Y4_GPIO_NUM       19
#define Y3_GPIO_NUM       18
#define Y2_GPIO_NUM        5

#define VSYNC_GPIO_NUM    25
#define HREF_GPIO_NUM     23
#define PCLK_GPIO_NUM     22

// =====================================================
// Camera settings
// =====================================================

#define CAM_W 160
#define CAM_H 120

#define RED_MIN_AREA 35
#define GREEN_MIN_AREA 35

// Scan only the lower-middle area instead of the full image.
#define ROI_Y_START 30

// Skip every other pixel for faster processing.
#define STEP_X 2
#define STEP_Y 2

// =====================================================
// RGB565 -> RGB888
// =====================================================

void rgb565_to_rgb(uint16_t pixel, int &r, int &g, int &b) {
  r = ((pixel >> 11) & 0x1F) << 3;
  g = ((pixel >> 5) & 0x3F) << 2;
  b = (pixel & 0x1F) << 3;
}

// =====================================================
// Color filters
// =====================================================

bool isRed(int r, int g, int b) {
  return (
    r > 100 &&
    g < 90 &&
    b < 90 &&
    r > g * 1.5 &&
    r > b * 1.5
  );
}

bool isGreen(int r, int g, int b) {
  return (
    g > 95 &&
    r < 120 &&
    b < 120 &&
    g > r * 1.25 &&
    g > b * 1.15
  );
}

// =====================================================
// Setup
// =====================================================

void setup() {
  Serial.begin(115200);
  delay(500);

  camera_config_t config;

  config.ledc_channel = LEDC_CHANNEL_0;
  config.ledc_timer = LEDC_TIMER_0;

  config.pin_d0 = Y2_GPIO_NUM;
  config.pin_d1 = Y3_GPIO_NUM;
  config.pin_d2 = Y4_GPIO_NUM;
  config.pin_d3 = Y5_GPIO_NUM;
  config.pin_d4 = Y6_GPIO_NUM;
  config.pin_d5 = Y7_GPIO_NUM;
  config.pin_d6 = Y8_GPIO_NUM;
  config.pin_d7 = Y9_GPIO_NUM;

  config.pin_xclk = XCLK_GPIO_NUM;
  config.pin_pclk = PCLK_GPIO_NUM;
  config.pin_vsync = VSYNC_GPIO_NUM;
  config.pin_href = HREF_GPIO_NUM;

  config.pin_sscb_sda = SIOD_GPIO_NUM;
  config.pin_sscb_scl = SIOC_GPIO_NUM;

  config.pin_pwdn = PWDN_GPIO_NUM;
  config.pin_reset = RESET_GPIO_NUM;

  config.xclk_freq_hz = 20000000;
  config.pixel_format = PIXFORMAT_RGB565;

  config.frame_size = FRAMESIZE_QQVGA;

  config.jpeg_quality = 12;
  config.fb_count = 1;

  esp_err_t err = esp_camera_init(&config);

  if (err != ESP_OK) {
    Serial.println("CAMERA_ERROR");
    delay(1000);
    ESP.restart();
  }

  sensor_t *s = esp_camera_sensor_get();

  if (s) {
    s->set_brightness(s, 0);
    s->set_contrast(s, 1);
    s->set_saturation(s, 1);

    s->set_whitebal(s, 1);
    s->set_awb_gain(s, 1);
    s->set_exposure_ctrl(s, 1);
    s->set_gain_ctrl(s, 1);
  }

  delay(500);
  Serial.println("ESP32_CAM_READY");
}

// =====================================================
// Loop
// =====================================================

void loop() {
  camera_fb_t *fb = esp_camera_fb_get();

  if (!fb) {
    Serial.println("NONE");
    delay(40);
    return;
  }

  long red_sum_x = 0;
  long green_sum_x = 0;

  int red_count = 0;
  int green_count = 0;

  for (int y = ROI_Y_START; y < CAM_H; y += STEP_Y) {
    for (int x = 0; x < CAM_W; x += STEP_X) {
      int idx = (y * CAM_W + x) * 2;

      if (idx + 1 >= fb->len) {
        continue;
      }

      uint16_t pixel = ((uint16_t)fb->buf[idx] << 8) | fb->buf[idx + 1];

      int r, g, b;
      rgb565_to_rgb(pixel, r, g, b);

      if (isRed(r, g, b)) {
        red_sum_x += x;
        red_count++;
      }

      if (isGreen(r, g, b)) {
        green_sum_x += x;
        green_count++;
      }
    }
  }

  esp_camera_fb_return(fb);

  if (red_count > RED_MIN_AREA && red_count >= green_count) {
    int red_x = red_sum_x / red_count;

    Serial.print("RED,");
    Serial.print(red_x);
    Serial.print(",");
    Serial.println(red_count);
  } else if (green_count > GREEN_MIN_AREA) {
    int green_x = green_sum_x / green_count;

    Serial.print("GREEN,");
    Serial.print(green_x);
    Serial.print(",");
    Serial.println(green_count);
  } else {
    Serial.println("NONE");
  }

  delay(35);
}

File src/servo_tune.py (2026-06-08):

from machine import I2C, PWM, Pin
import time

# =====================================================
# Pins
# =====================================================

SERVO_PIN = 14

SDA_PIN = 4
SCL_PIN = 5


# =====================================================
# Servo tune settings
# =====================================================

SERVO_MIN = 30
SERVO_MAX = 100
SERVO_CENTER = 65

SERVO_REVERSE = True

# How long should PID run?
PID_START_TIME_MS = 3000

# Servo angle to test after PID finishes.
TEST_SERVO_ANGLE = 80

# Keep the servo at the test angle.
HOLD_AFTER_TEST = True


# =====================================================
# PID settings
# =====================================================

KP = 1.8
KI = 0.00
KD = 0.25


# =====================================================
# Servo
# =====================================================

servo = PWM(Pin(SERVO_PIN))
servo.freq(50)


def set_servo_angle(angle):
    angle = max(SERVO_MIN, min(SERVO_MAX, angle))

    min_us = 500
    max_us = 2500

    pulse_us = min_us + (angle / 180) * (max_us - min_us)
    duty = int((pulse_us / 20000) * 65535)

    servo.duty_u16(duty)


def servo_center():
    set_servo_angle(SERVO_CENTER)


def set_servo_pid(correction):
    if SERVO_REVERSE:
        servo_angle = SERVO_CENTER - correction
    else:
        servo_angle = SERVO_CENTER + correction

    servo_angle = max(SERVO_MIN, min(SERVO_MAX, servo_angle))
    set_servo_angle(servo_angle)

    return servo_angle


# =====================================================
# MPU9250
# =====================================================

i2c = I2C(0, sda=Pin(SDA_PIN), scl=Pin(SCL_PIN), freq=400000)

devices = i2c.scan()
print("I2C devices:", devices)

MPU_ADDR = 0x68

if MPU_ADDR not in devices:
    print("0x68 not found, trying 0x69...")
    MPU_ADDR = 0x69

if MPU_ADDR not in devices:
    print("MPU9250 not found. Check the wiring.")
    while True:
        servo_center()
        time.sleep(1)

# MPU wake up
i2c.writeto_mem(MPU_ADDR, 0x6B, b"\x00")
time.sleep(0.05)

# Gyro +-250 dps
i2c.writeto_mem(MPU_ADDR, 0x1B, b"\x00")

# Accel +-2g
i2c.writeto_mem(MPU_ADDR, 0x1C, b"\x00")


def read_word(reg):
    high = i2c.readfrom_mem(MPU_ADDR, reg, 1)[0]
    low = i2c.readfrom_mem(MPU_ADDR, reg + 1, 1)[0]

    value = (high << 8) | low

    if value > 32767:
        value -= 65536

    return value


def read_gyro():
    gx_raw = read_word(0x43)
    gy_raw = read_word(0x45)
    gz_raw = read_word(0x47)

    gx = gx_raw / 131.0
    gy = gy_raw / 131.0
    gz = gz_raw / 131.0

    return gx, gy, gz


def calibrate_gyro(samples=400):
    print("Gyro calibration starting. Keep the robot still...")

    gx_sum = 0
    gy_sum = 0
    gz_sum = 0

    for _ in range(samples):
        gx, gy, gz = read_gyro()

        gx_sum += gx
        gy_sum += gy
        gz_sum += gz

        time.sleep(0.004)

    print("Calibration complete.")

    return gx_sum / samples, gy_sum / samples, gz_sum / samples


# =====================================================
# PID
# =====================================================

integral = 0.0
last_error = 0.0


def pid_control(error, dt):
    global integral, last_error

    integral += error * dt
    integral = max(-50, min(50, integral))

    derivative = (error - last_error) / dt if dt > 0 else 0

    output = (KP * error) + (KI * integral) + (KD * derivative)

    last_error = error

    return output


def reset_pid():
    global integral, last_error

    integral = 0.0
    last_error = 0.0


# =====================================================
# Main program
# =====================================================

yaw = 0.0
target_yaw = 0.0

try:
    servo_center()
    time.sleep(0.5)

    gx_bias, gy_bias, gz_bias = calibrate_gyro()

    print("SERVO TUNE MODE STARTED")
    print("First it will hold straight with PID.")
    print("Then it will move to TEST_SERVO_ANGLE.")
    print("SERVO_MIN:", SERVO_MIN)
    print("SERVO_MAX:", SERVO_MAX)
    print("SERVO_CENTER:", SERVO_CENTER)
    print("TEST_SERVO_ANGLE:", TEST_SERVO_ANGLE)

    start_ms = time.ticks_ms()
    last_time = time.ticks_us()

    mode = "PID"

    while True:
        now_us = time.ticks_us()
        dt = time.ticks_diff(now_us, last_time) / 1000000.0
        last_time = now_us

        if dt <= 0:
            dt = 0.001

        gx, gy, gz = read_gyro()
        gz_corrected = gz - gz_bias

        if abs(gz_corrected) < 0.4:
            gz_corrected = 0

        yaw += gz_corrected * dt

        if mode == "PID":
            error = target_yaw - yaw
            correction = pid_control(error, dt)

            servo_angle = set_servo_pid(correction)

            if time.ticks_diff(time.ticks_ms(), start_ms) >= PID_START_TIME_MS:
                print("PID complete.")
                print("Switching to fixed servo angle:", TEST_SERVO_ANGLE)

                reset_pid()
                mode = "TEST_ANGLE"

        elif mode == "TEST_ANGLE":
            set_servo_angle(TEST_SERVO_ANGLE)

            if HOLD_AFTER_TEST:
                pass

        print(
            "Mode:", mode,
            "| Yaw:", round(yaw, 2),
            "| TestAngle:", TEST_SERVO_ANGLE
        )

        time.sleep_ms(50)

except KeyboardInterrupt:
    print("Program stopped.")

finally:
    servo_center()
